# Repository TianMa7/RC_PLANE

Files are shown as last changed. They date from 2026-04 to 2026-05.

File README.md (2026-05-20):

# Fixed-Wing RC Aircraft

<table>
  <tr>
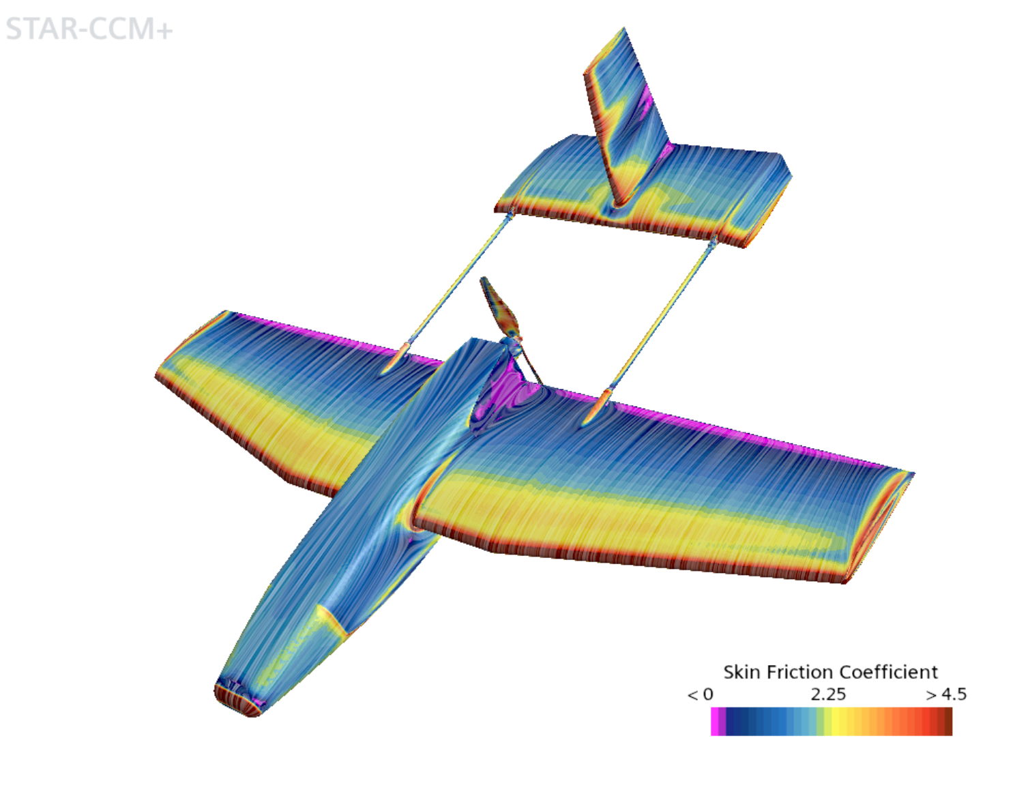
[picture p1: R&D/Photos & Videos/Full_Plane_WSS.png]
    <td width="21.25%"></td>
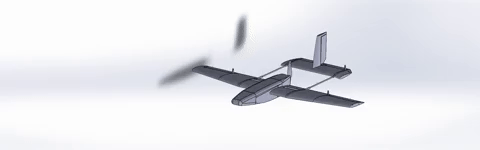
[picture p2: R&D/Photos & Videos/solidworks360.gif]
    <td width="50%"></td>
  </tr>
</table>

## ✈️ Summary and Takeaways
**Mission Goal:** Design and fly an RC Aircraft capable of fly-by-wire controls and stable flight. Learn about nuances of designing systems capable of withstanding the complex dynamics of flight. 

### 📋 Technical Specifications
| Category | Metric |
| :--- | :--- |
| **Wingspan** | 99.25cm |
| **Airfoil** | NACA 2412 |
| **Weight** | 837g |
| **Motor** | 2212 1400kv BLDC Motor |
| **Battery** | 3S 2200 mAh LIPO |
| **Material Cost** | $157 CAD |
| **Materials List** | [Download Excel Sheet](https://github.com/TianMa7/RC_PLANE/raw/master/HARDWARE/RC%20Plane%20-%20Major%20Item%20List.xlsx)

---

### 🛠️ Design & Aerodynamics
<table>
  <tr>
    <td width="50%">
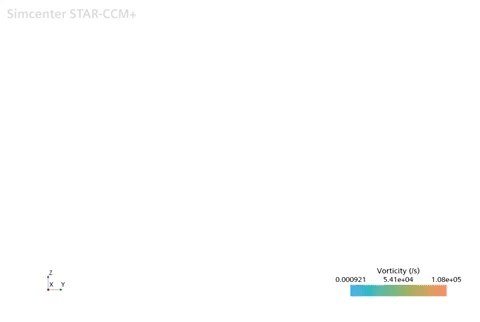
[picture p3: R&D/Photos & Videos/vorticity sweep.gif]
      
      <br><em>Vorticity X Sweep</em>
    </td>
    <td width="50%">
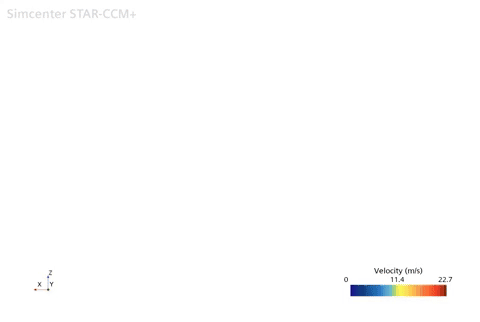
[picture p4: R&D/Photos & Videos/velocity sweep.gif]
      
      <br><em>Velocity Y Sweep</em>
    </td>
  </tr>
</table>

* **Research & Development:** Selection of the NACA 2412 airfoil was driven by the need for a stable lift-to-drag ratio across a variety of Reynolds numbers suitable for small-scale RC flight. Pull-Pull control systems were implemented to reduce and optimize weight distribution.
* **Simulation (CFD):** Star-CCM+ CFD was used to validate design choices and identify potential changes. It was also used to calculate the aerodynamic balance point to determine weight distribution.
* **Mechanical (CAD):** SolidWorks was used to model the aircraft and internal components. Designs were originally considered to be a combination of laser cut balsa wood, composite construction, and 3D printing. Project was gradually descoped to 3D printing and composite components to save manufacturing time and complexity.

### 💻 Systems & Integration
* **Scope:** Development of electronics and control software capable of producing stable, controllable flight for plane. Controls are fly-by-wire for pitch and roll, and raw input for yaw. Communication between radio rx/tx was beyond the scope of the project.
* **Control Logic:** RTOS Implementation of a PID-based control loop taking input from blended IMU data with Mahony filter as well as user input from rc controller. Uses PID loop to maintain stability when external forces are acting upon it.
* **Electronics:** Protoboard containing esp32c3, lsm6ds3, and other components. Controlled a BLDC motor as well as 3 MG90s Servos. A full material list and breakdown can be found [HERE](https://github.com/TianMa7/RC_PLANE/raw/master/HARDWARE/RC%20Plane%20-%20Major%20Item%20List.xlsx).

### 🚀 Validation & Flight Results
* **Pre-Flight:** Aircraft was 16% below maximum calculated weight. Static thrust and controls testing validated structural integrity of the body as well as the electronics. 
* **Maiden Flight:** [Insert Date]
* **Outcome:** EMF interference towards unshielded electronic devices (servo, imu) theorized to be the reason behind unpredictable and unlevel flight/crash. Issue was not flagged as interference only became an issue when motor was facing load from propeller. Bench testing was primarily not conducted with propeller on for safety. Future designs should explore methods of reducing such interference, as well as creating more robust control surfaces and improving software design. Mechanical design will focus on improving aerodynamic efficiency as well as shifting CoG forward for better stability.

---

### 📷 Media Gallery

<table>
  <tr>
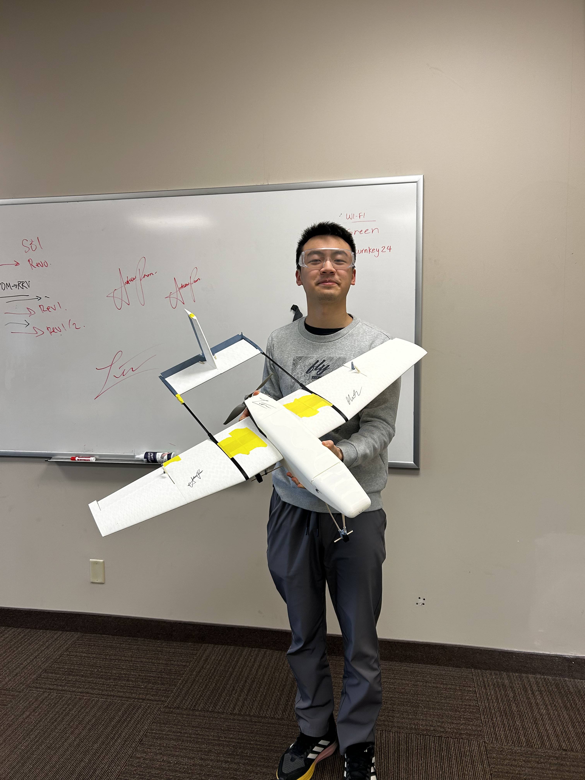
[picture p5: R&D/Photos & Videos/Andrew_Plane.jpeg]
Andrew Plane
    <td width="33%"><br><em>Andrew Plane</em></td>
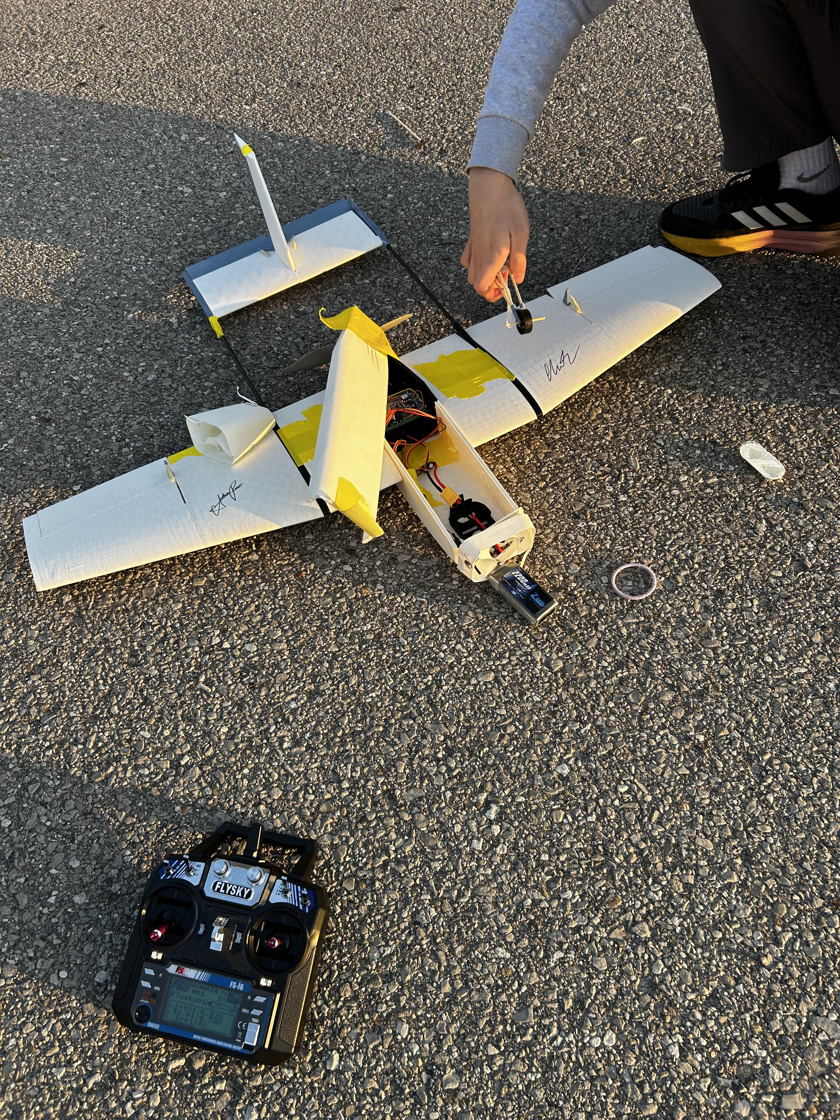
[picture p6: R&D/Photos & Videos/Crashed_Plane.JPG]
Crashed Plane
    <td width="33%"><br><em>Crashed Plane</em></td>
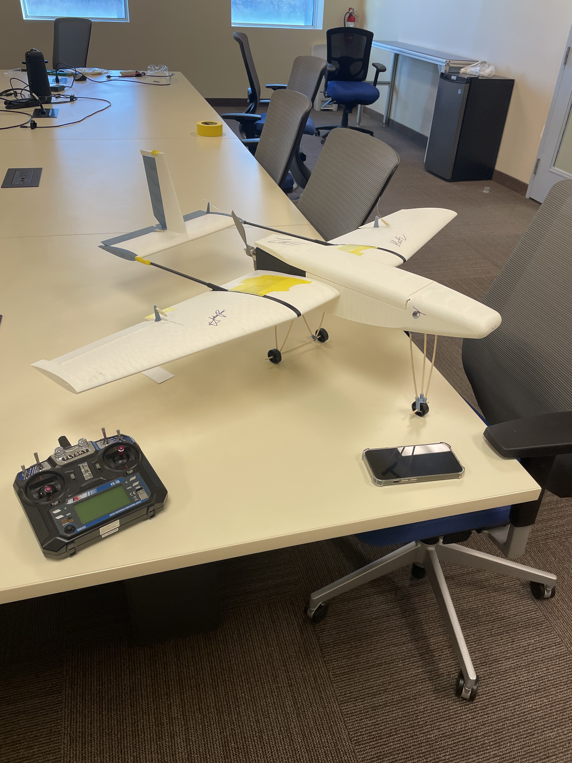
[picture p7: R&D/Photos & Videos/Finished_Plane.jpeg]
Finished Plane
    <td width="33%"><br><em>Finished Plane</em></td>
  </tr>
  <tr>
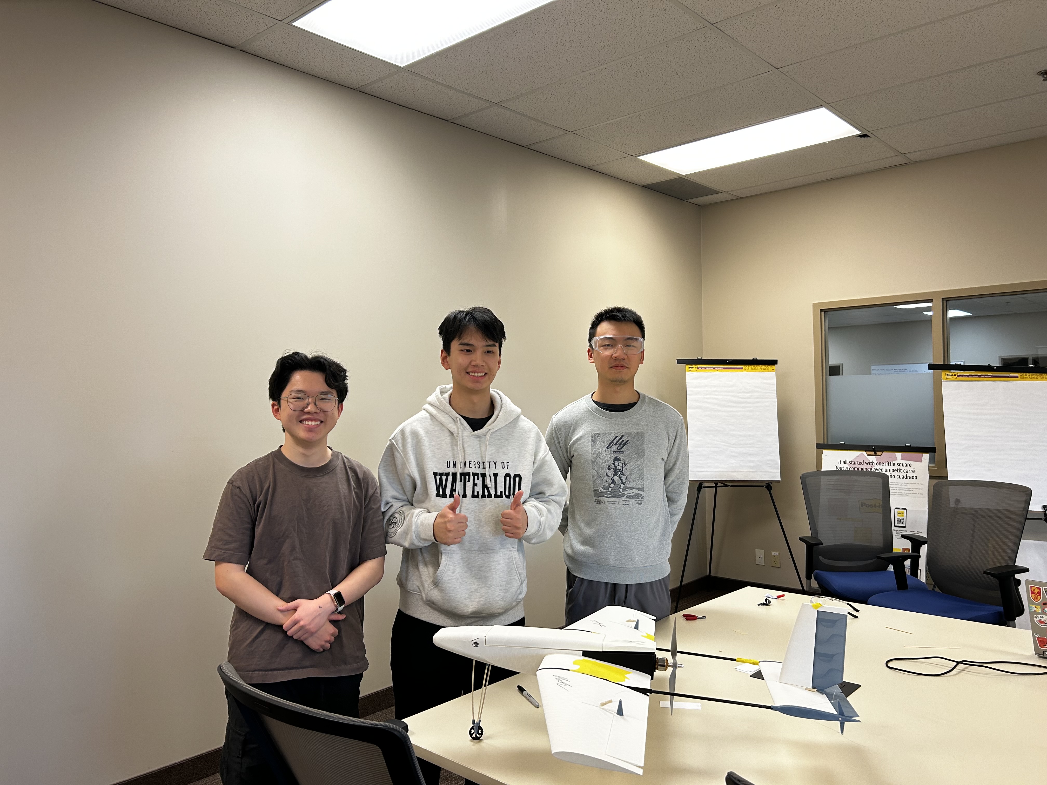
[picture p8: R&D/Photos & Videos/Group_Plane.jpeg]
Group Plane
    <td width="33%"><br><em>Group Plane</em></td>
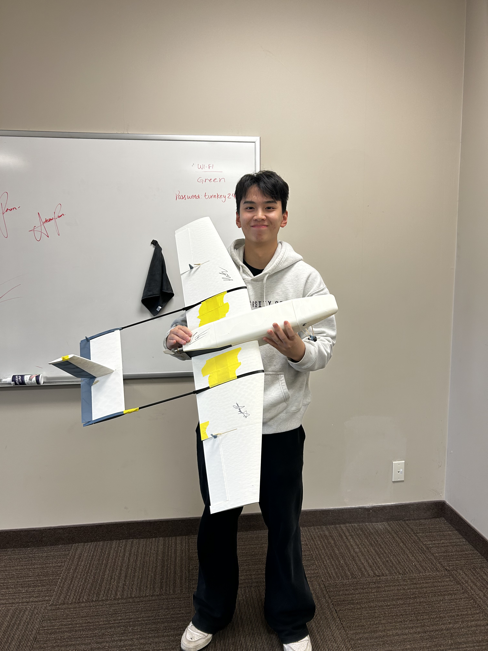
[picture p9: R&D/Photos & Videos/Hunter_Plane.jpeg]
Hunter Plane
    <td width="33%"><br><em>Hunter Plane</em></td>
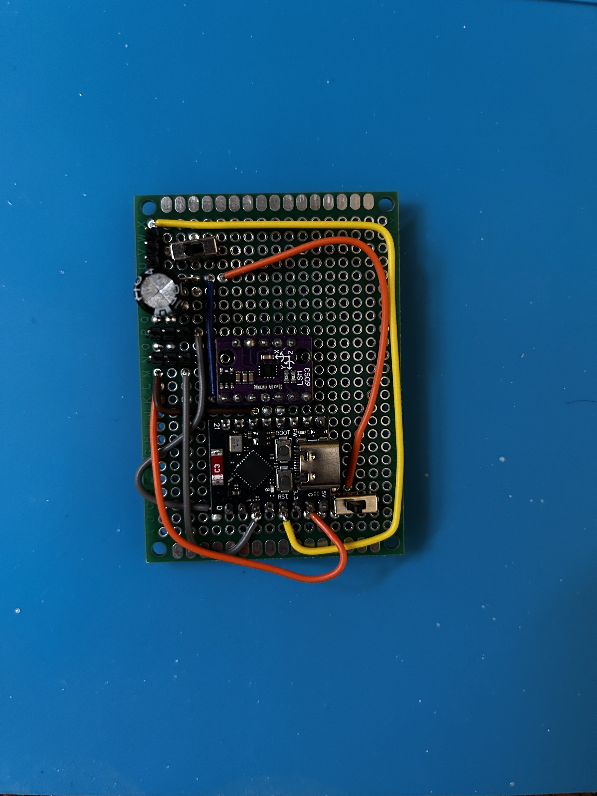
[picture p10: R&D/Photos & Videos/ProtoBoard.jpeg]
Protoboard
    <td width="33%"><br><em>Protoboard</em></td>
  </tr>
  <tr>
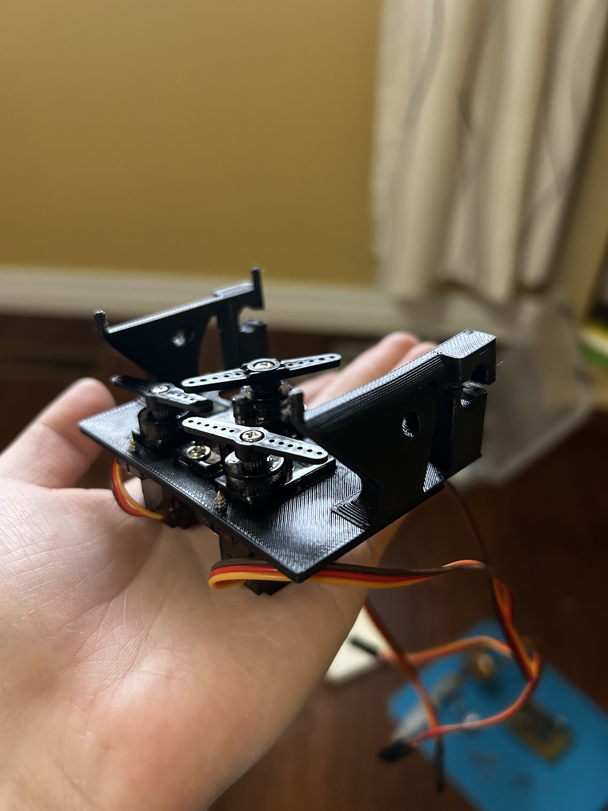
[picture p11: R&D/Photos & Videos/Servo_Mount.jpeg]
Servo Mount
    <td width="33%"><br><em>Servo Mount</em></td>
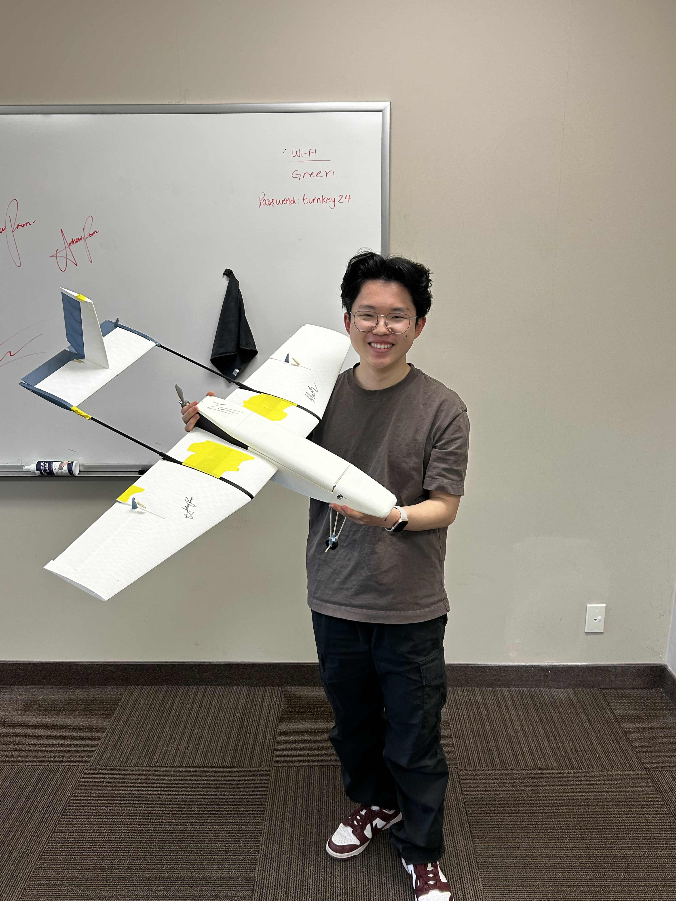
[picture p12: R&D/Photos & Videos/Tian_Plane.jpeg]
Tian Plane
    <td width="33%"><br><em>Tian Plane</em></td>
    <td width="33%">
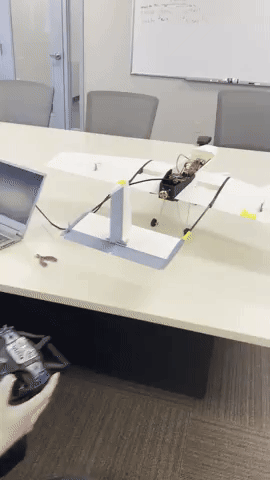
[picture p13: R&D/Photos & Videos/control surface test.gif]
      
      <br><em>Ailerons Test</em>
    </td>
  </tr>
  <tr>
    <td width="33%">
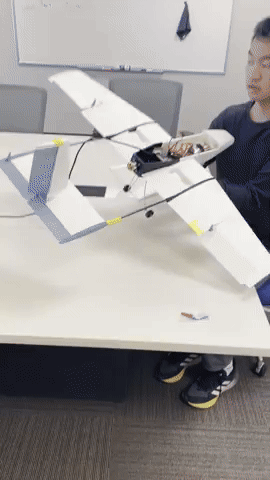
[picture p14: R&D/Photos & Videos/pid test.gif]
      
      <br><em>Auto Balancing Test</em>
    </td>
    <td width="33%">
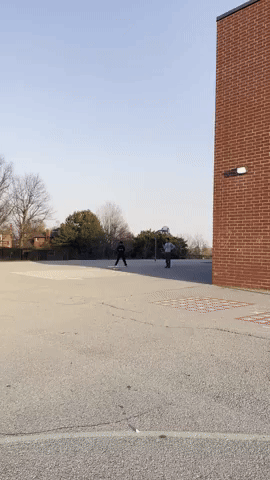
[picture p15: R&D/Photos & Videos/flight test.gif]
      
      <br><em>Flight Test</em>
    </td>
    <td width="33%">
      
      <br><em>360 Overview</em>
    </td>
  </tr>
</table>

---
*Developed by Tian Ma, Hunter Liu, Andrew Poon*

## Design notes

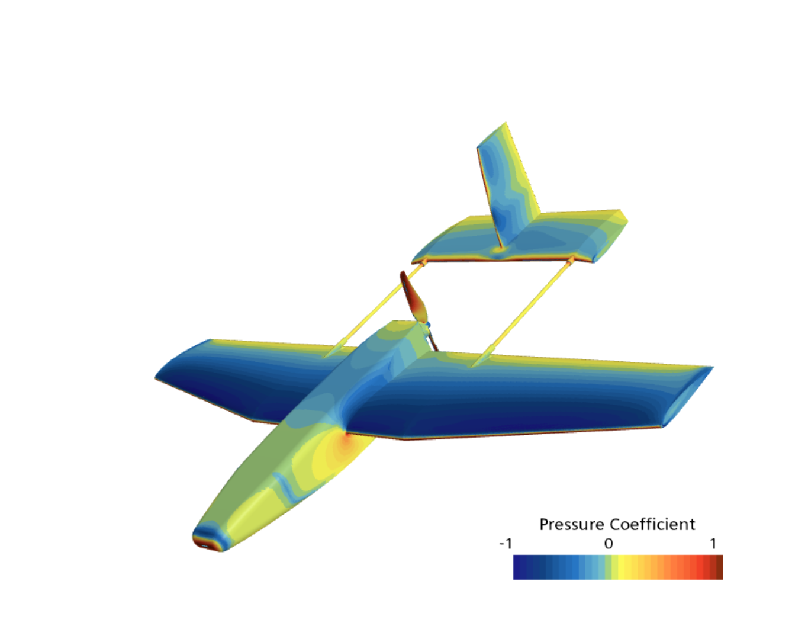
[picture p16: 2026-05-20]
R&D/Photos & Videos/Full_Plane_Pressure_Coefficient.png

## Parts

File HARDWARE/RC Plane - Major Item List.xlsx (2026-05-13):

Item name | Qty | Cost Per Unit | Supplier | Type
ESP32-C3 Microcontroller | 1 | $3.00 | AliExpress | Electronics
LSM6DS3 IMU | 1 | $3.00 | AliExpress | Electronics
2212 1400kv BLDC Motor | 1 | $4.00 | AliExpress | Electronics
8060 Propeller | 1 | $1.25 | AliExpress | Electronics
30a ESC | 1 | $6.00 | AliExpress | Electronics
2200mAh 3s LiPo Battery | 1 | $25.00 | Amazon | Electronics
FlySky FS-i6 6CH RC Controller/Reciever | 1 | $69.00 | AliExpress | Electronics
MG90S Servo | 3 | $4.00 | AliExpress | Electronics
6mm Pultruded carbon tube | 2 | $7.00 | Composites Canada | Material
Creality LW-PLA 1kg roll | 1 | $24.00 | Creality Canada | Material
TPU | 1 | $0.00 | N/A | Material
Generic PLA | 1 | $11.00 | Creality Canada | Material
 | Total Cost | $157.25

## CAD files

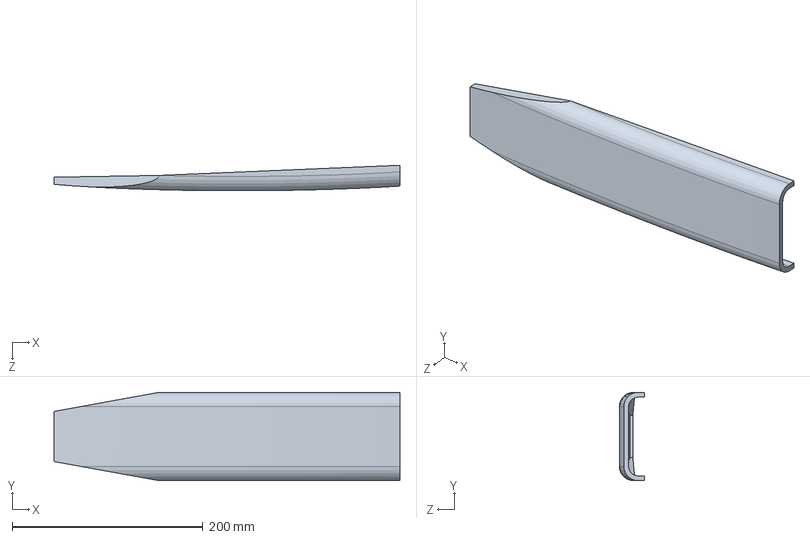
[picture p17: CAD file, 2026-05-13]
HARDWARE/SolidWorks/fuselage_v3_lid_01.SLDPRT
362.6 x 92.5 x 26.7 mm

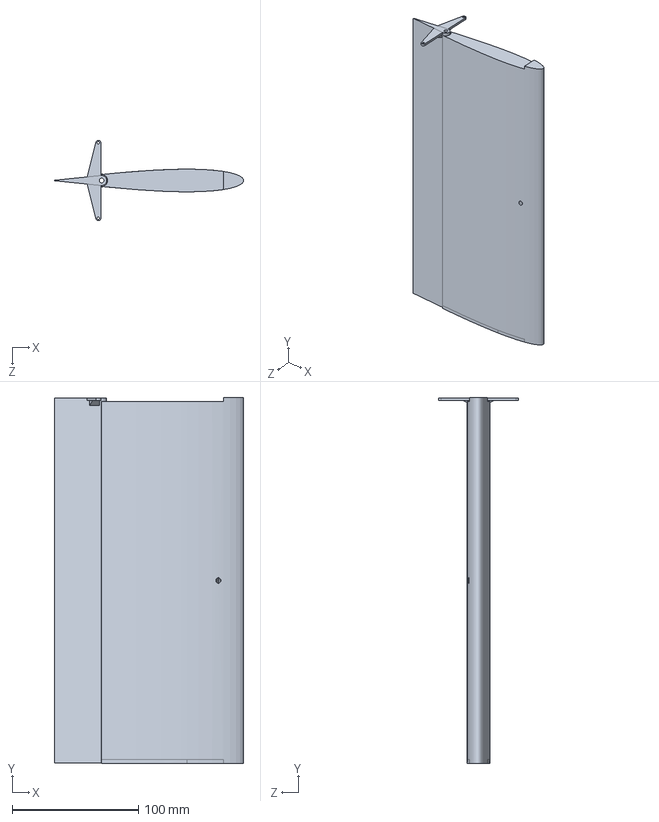
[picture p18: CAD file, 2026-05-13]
HARDWARE/SolidWorks/elevator2.SLDPRT
150.0 x 290.0 x 63.8 mm

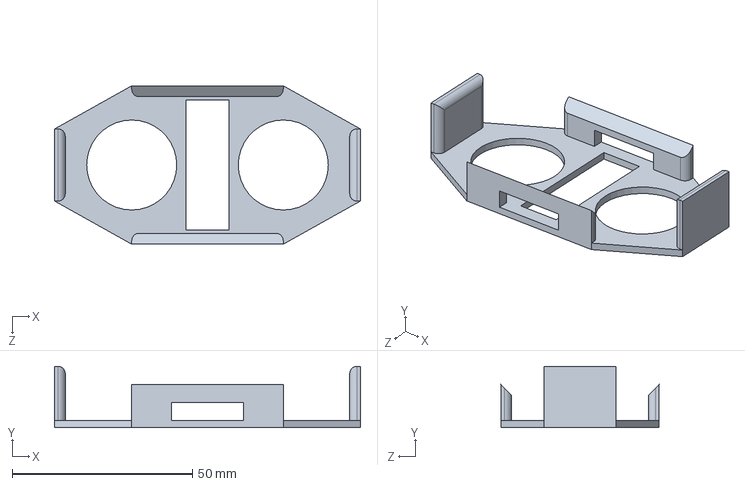
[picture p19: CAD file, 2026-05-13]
HARDWARE/SolidWorks/battery-mount-version-00_PRINT.SLDPRT
85.0 x 17.0 x 44.0 mm

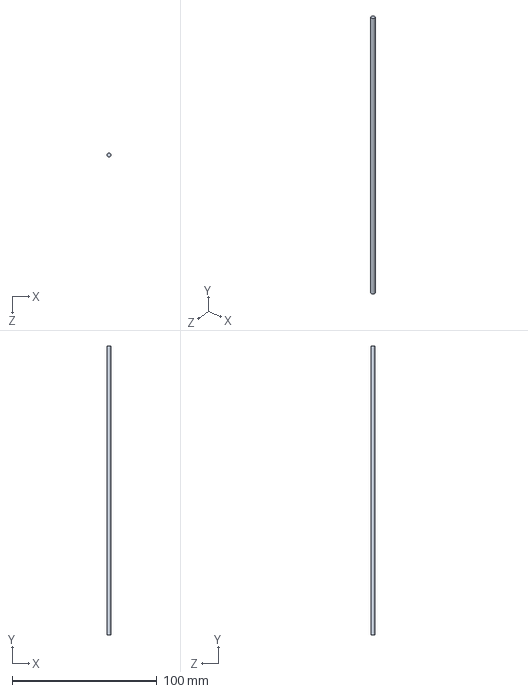
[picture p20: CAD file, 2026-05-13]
HARDWARE/SolidWorks/BAMBOO-SKEWER-3MM.SLDPRT
3.00 x 200.0 x 3.00 mm

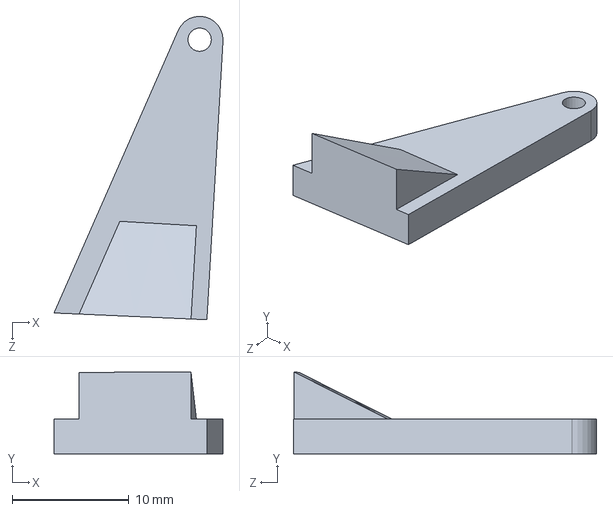
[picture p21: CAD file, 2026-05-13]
HARDWARE/SolidWorks/WingHornLower.SLDPRT
14.5 x 7.00 x 26.0 mm

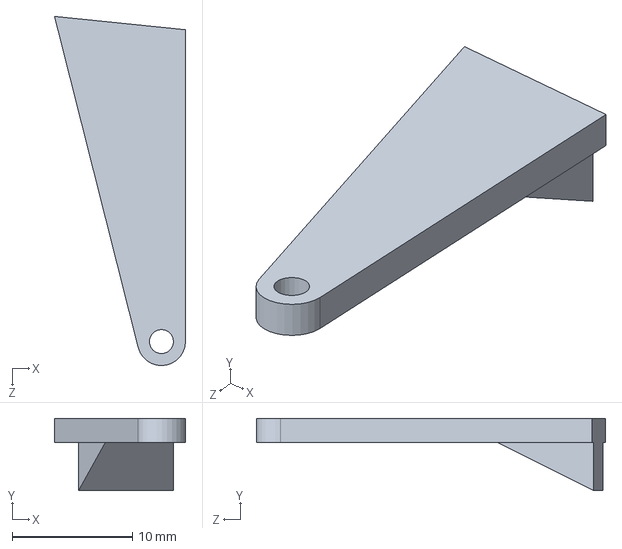
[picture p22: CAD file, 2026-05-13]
HARDWARE/SolidWorks/AileronHornUpper.SLDPRT
10.9 x 6.00 x 29.0 mm

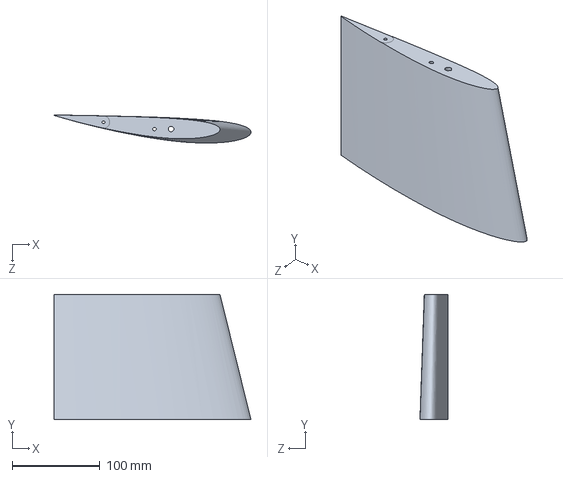
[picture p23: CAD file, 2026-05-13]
HARDWARE/SolidWorks/Body2.SLDPRT
224.2 x 142.6 x 32.0 mm

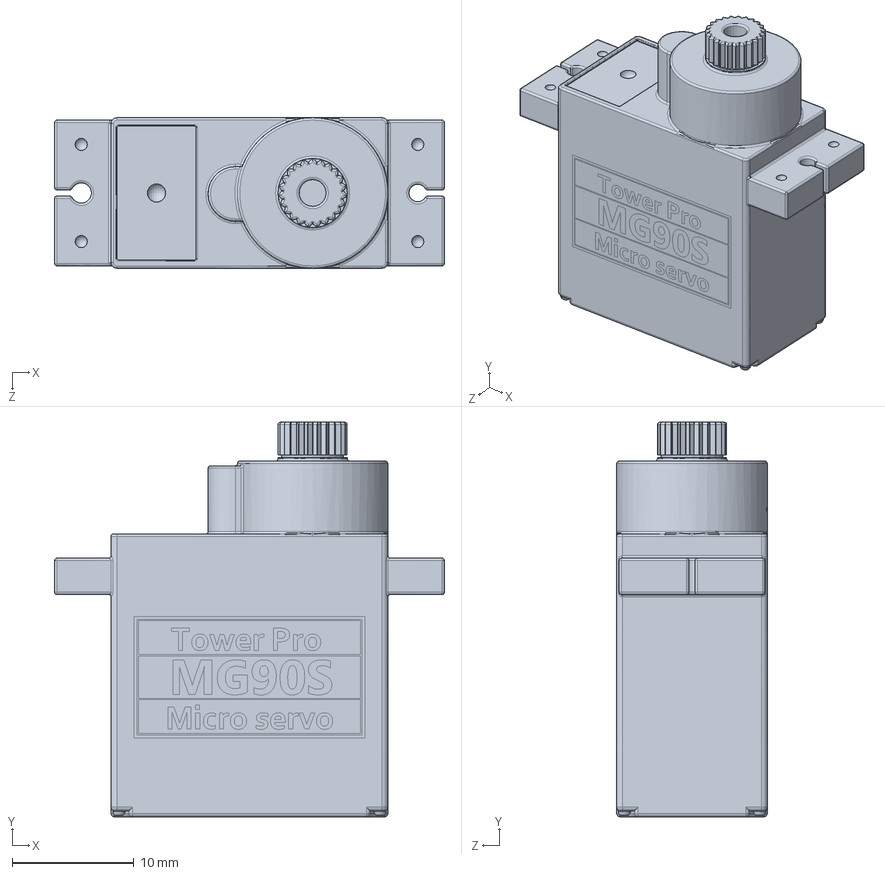
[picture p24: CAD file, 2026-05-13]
HARDWARE/SolidWorks/Tower-Pro-MG90S.SLDPRT
32.1 x 32.5 x 12.4 mm

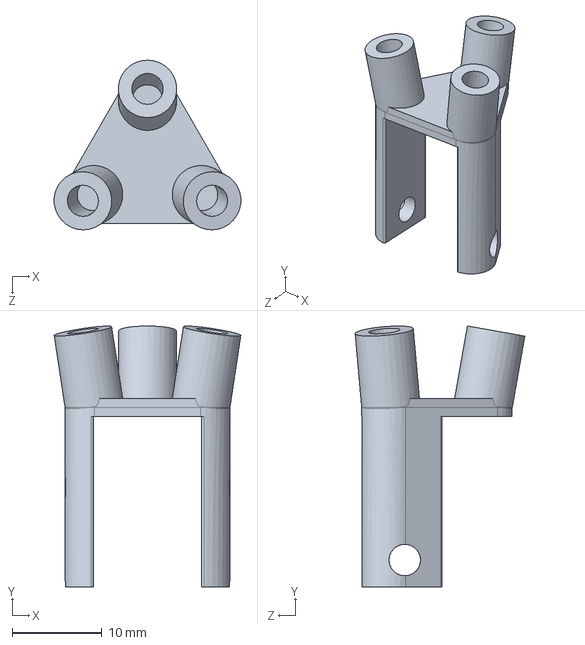
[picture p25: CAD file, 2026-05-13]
HARDWARE/SolidWorks/nose_gear.SLDPRT
20.8 x 29.1 x 18.9 mm

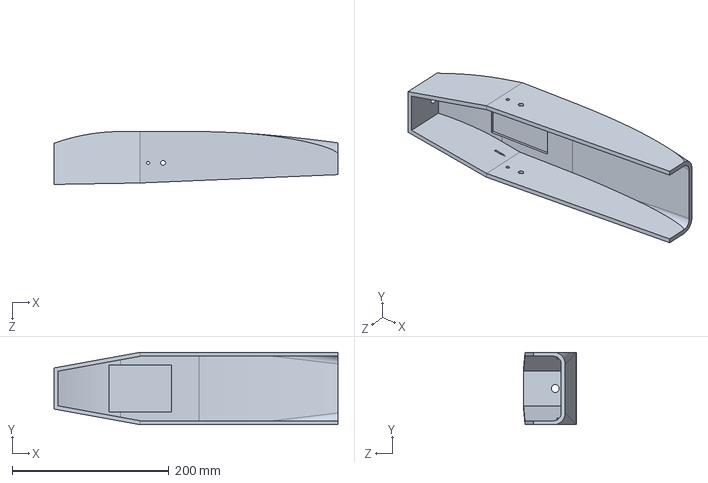
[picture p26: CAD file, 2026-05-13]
HARDWARE/SolidWorks/fuselage_v3_body_01.SLDPRT
362.6 x 92.5 x 67.5 mm

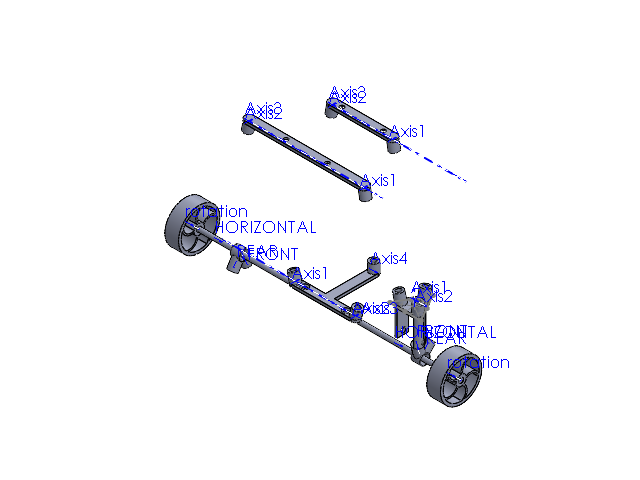
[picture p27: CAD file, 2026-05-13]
HARDWARE/SolidWorks/landing gear comp.SLDASM
BAMBOO-SKEWER-3MM
TIRE-30MM x 2
MOUNTING CONNECTOR x 2
ROD-CONNECTOR-3.5MM x 2
nose_gear
MOUNTING CONNECTOR-nose

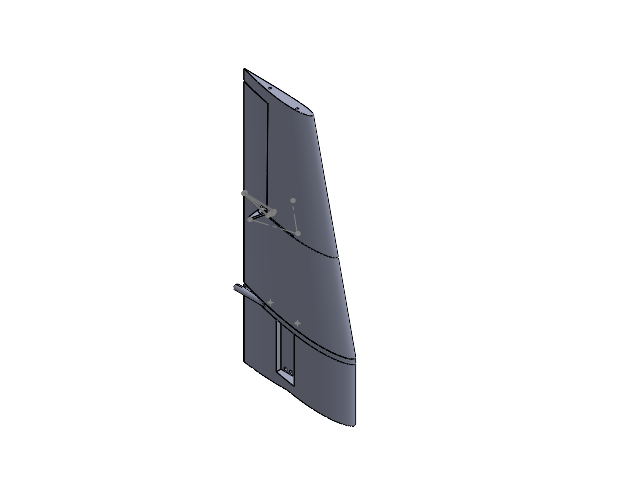
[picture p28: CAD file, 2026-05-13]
HARDWARE/SolidWorks/Wing_asssy_v1.SLDASM
Wing_MidSection_v1
Wingtip_v1
wing_root_v2

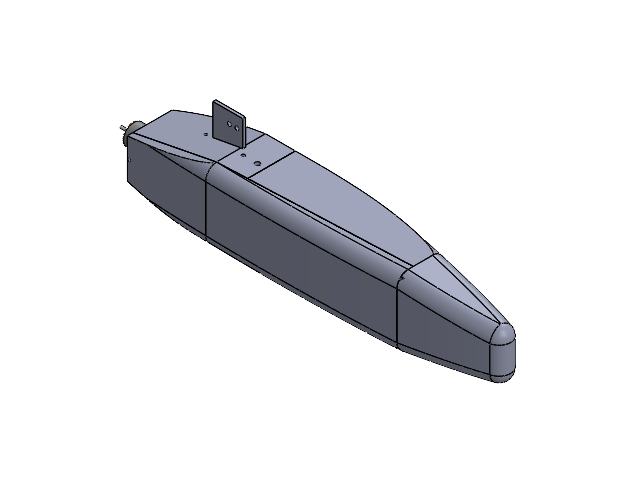
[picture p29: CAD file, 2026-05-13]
HARDWARE/SolidWorks/fuselage_asm.SLDASM
fuselage_V3
servo-mount-version-02_PRINT
DOTTED PCB 5 7 CM
Tower-Pro-MG90S x 3
MG90S 9g Micro Servo Medium Horn 12 holes x 3
servo-mount-rings x 4
motor-mount-version-03
Motor_BLDC_2212,6T_2200KV
Generic.40A.ESC.stp
battery-mount-version-00_PRINT

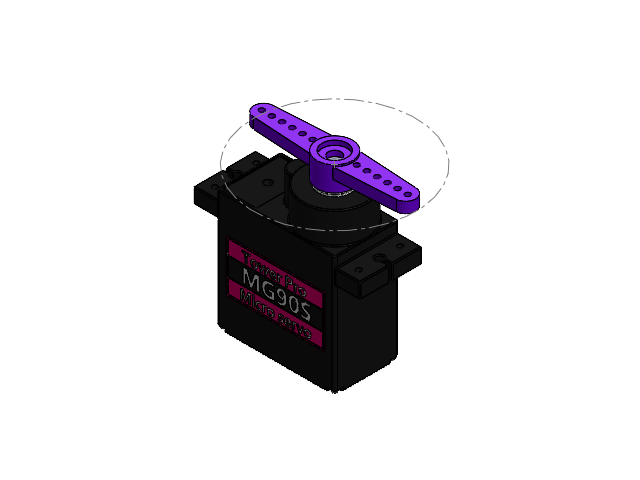
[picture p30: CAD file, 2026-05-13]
HARDWARE/SolidWorks/mg90s_assembly.SLDASM
Tower-Pro-MG90S
MG90S 9g Micro Servo Medium Horn 12 holes

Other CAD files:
HARDWARE/SolidWorks/MirrorWing_asssy_v1.SLDASM
HARDWARE/SolidWorks/Full_Plane_Assy.SLDASM
HARDWARE/SolidWorks/servo_asm_2.SLDASM
HARDWARE/SolidWorks/AileronHornLower.SLDPRT
HARDWARE/3mf/Full_Plane_Assy.3mf
HARDWARE/SolidWorks/8060_propeller.SLDPRT
HARDWARE/SolidWorks/Body1.SLDPRT
HARDWARE/SolidWorks/Carbon_rods.SLDPRT
HARDWARE/SolidWorks/DOTTED PCB 5 7 CM.SLDPRT
HARDWARE/SolidWorks/Elavator_attachment.SLDPRT
HARDWARE/SolidWorks/Elevator_v1.SLDPRT
HARDWARE/SolidWorks/Generic.40A.ESC.stp
HARDWARE/SolidWorks/MG90S 9g Micro Servo Medium Horn 12 holes.SLDPRT
HARDWARE/SolidWorks/MOUNTING CONNECTOR-nose.SLDPRT
HARDWARE/SolidWorks/MOUNTING CONNECTOR.SLDPRT
HARDWARE/SolidWorks/MirrorElavator_attachment.SLDPRT
HARDWARE/SolidWorks/MirrorWing_MidSection_v1.SLDPRT
HARDWARE/SolidWorks/MirrorWingtip_v1.SLDPRT
HARDWARE/SolidWorks/Mirrorwing_root_v2.SLDPRT
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

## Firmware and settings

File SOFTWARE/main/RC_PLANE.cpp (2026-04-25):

/* =============================================================
 * GENERAL HEADERS
 * ============================================================= */
#include <algorithm>
#include <cmath>

/* =============================================================
 * ESP32S3 SPECIFIC HEADERS
 * ============================================================= */
#include "esp_log.h"
#include "freertos/FreeRTOS.h"
#include "freertos/task.h"
#include "freertos/semphr.h"
#include <driver/uart.h>

/* =============================================================
 * SENSOR AND CONTROL HEADERS
 * ============================================================= */
#include "controlTasks.h"
#include "driver/i2c_master.h"
#include "lsm6ds3.h"
#include "mahony_filter.h"
#include "iot_servo.h"
#include "pid.h"


extern "C"
{
#include "ibus/ibus.h"
}

extern "C" void app_main()
{
    ESP_LOGI(TAG, "Starting RC Plane Application");


    /* ---- I2C master bus ---- */
    i2c_master_bus_config_t i2c_mst_config =
    {
        .i2c_port = I2C_NUM_0,
        .sda_io_num = I2C_MASTER_SDA_IO,
        .scl_io_num = I2C_MASTER_SCL_IO,
        .clk_source = I2C_CLK_SRC_DEFAULT,
        .glitch_ignore_cnt = 7,
        .intr_priority = 0,
        .trans_queue_depth = 0,
        .flags =
     {
            .enable_internal_pullup = true,
            .allow_pd = false
        },
    };

    i2c_master_bus_handle_t bus_handle;
    esp_err_t ret = i2c_new_master_bus(&i2c_mst_config, &bus_handle);
    if (ret != ESP_OK)
    {
        ESP_LOGE(TAG, "I2C bus failed: %s", esp_err_to_name(ret));
        while (true)
        {
            vTaskDelay(pdMS_TO_TICKS(1000));
        }
    }
    ESP_LOGI(TAG, "I2C bus OK");
    /* ---- end I2C master bus ---- */

    /* ---- LSM6DS3 sensor ---- */
    lsm6ds3_config_t imu_config =
    {
        .i2c_bus_handle = bus_handle,
        .i2c_freq_hz    = I2C_MASTER_FREQ_HZ,
        .device_address  = LSM6DS3_ADDR_SA0_HIGH,
    };

    lsm6ds3_handle_t imu_handle;
    ret = lsm6ds3_init(&imu_config, &imu_handle);
    if (ret != ESP_OK)
    {
        ESP_LOGE(TAG, "LSM6DS3 init failed: %s", esp_err_to_name(ret));
        i2c_del_master_bus(bus_handle);
        while (true)
        {
            vTaskDelay(pdMS_TO_TICKS(1000));
        }
    }
    ESP_LOGI(TAG, "LSM6DS3 OK");
    /* ---- end LSM6DS3 sensor ---- */



    /* ---- servo control ---- */
    /* Adjust frequency as needed */
    servo_config_t servo_config = {
        .max_angle = 180,
        .min_width_us = 500,
        .max_width_us = 2500,
        .freq = 50,
        .timer_number = LEDC_TIMER_0,
        .channels = {
            .servo_pin =
         {
                AILERON_SERVO_PIN,
                ELEVATOR_SERVO_PIN,
            },
            .ch =
         {
                LEDC_CHANNEL_0,
                LEDC_CHANNEL_1
            }
        },
        .channel_number = 2,
    };

    ret = iot_servo_init(LEDC_LOW_SPEED_MODE, &servo_config);
    if (ret != ESP_OK)
    {
        ESP_LOGE(TAG, "Servo init failed: %s", esp_err_to_name(ret));
        lsm6ds3_deinit(imu_handle);
        i2c_del_master_bus(bus_handle);
        while (true)
        {
            vTaskDelay(pdMS_TO_TICKS(1000));
        }
    }
    ESP_LOGI(TAG, "Servo OK");
    /* ---- end servo control ---- */

    /* ---- IBUS setup ---- */
    uart_lowlevel_config config;
    config.port = IBUS_UART;
    config.tx_pin = UART_PIN_NO_CHANGE; // Not transmitting, so leave TX unconfigured
    config.rx_pin = IBUS_RX_PIN;
    ibus_context_t cfx = ibus_init(&config);
    if (cfx == nullptr)
    {
        ESP_LOGE(TAG, "IBUS init failed");
        ibus_set_channel_handler(cfx, nullptr, nullptr); // Unset handler if init failed
        iot_servo_deinit(LEDC_LOW_SPEED_MODE);
        lsm6ds3_deinit(imu_handle);
        i2c_del_master_bus(bus_handle);
        while (true)
        {
            vTaskDelay(pdMS_TO_TICKS(1000));
        }
    }
    ESP_LOGI(TAG, "IBUS OK");
    /* ---- end IBUS setup ---- */

    static CONTROLTASKS controlTasks(imu_handle);
    ibus_set_channel_handler(cfx, CONTROLTASKS::channel_handler, nullptr);

    BaseType_t ok = xTaskCreate(
        CONTROLTASKS::flightControlTask, //function
        "flight_control_task", //task name
        4096, //allocated memory
        nullptr, //pvParameters
        10, //priority, higher is more important
        nullptr //task handler
    );

    if (ok != pdPASS)
    {
        ESP_LOGE(TAG, "failed to create flight control task");
        while (true)
        {
            vTaskDelay(pdMS_TO_TICKS(1000));
        }
    }

    BaseType_t log_ok = xTaskCreate(
    CONTROLTASKS::logTask,
    "flight_log_task",
    4096,
    nullptr,
    3,
    nullptr
    );

    if (log_ok != pdPASS)
    {
        ESP_LOGE(TAG, "failed to create log task");
    }



}

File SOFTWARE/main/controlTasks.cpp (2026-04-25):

#include "controlTasks.h"
SemaphoreHandle_t CONTROLTASKS::FlightDataMutex = nullptr;
FlightData CONTROLTASKS::planeData = {};
MahonyFilter* CONTROLTASKS::mahony = nullptr;
lsm6ds3_handle_t CONTROLTASKS::imu_handle = nullptr;
PID* CONTROLTASKS::aileronPID = nullptr;
PID* CONTROLTASKS::elevatorPID = nullptr;

CONTROLTASKS::CONTROLTASKS(lsm6ds3_handle_t &imu)
{
        /* Create mutex to lock flight data */
        FlightDataMutex = xSemaphoreCreateMutex();
        if (FlightDataMutex == nullptr)
        {
                ESP_LOGE(TAG, "Failed to create mutex: flightDataMutex");
                return;
        }

        /* init imu and mahony filter */
        imu_handle = imu;

        // Baseline Mahony gains from loop rate for fixed-wing bench bring-up.
        // Formula: kp ~= 2 / settle_time, ki ~= kp / loop_hz.
        const float loop_hz = 1000.0f / planeData.flightControlTaskPeriod_ms;
        const float settle_time_s = 1.2f;
        const float mahony_kp = std::clamp(2.0f / settle_time_s, 0.8f, 2.5f);
        const float mahony_ki = std::clamp(mahony_kp / loop_hz, 0.001f, 0.05f);

        mahony = new MahonyFilter(mahony_kp, mahony_ki);

        if (imu_handle == nullptr || mahony == nullptr)
        {
                ESP_LOGE(TAG, "Failed to create MahonyFilter");
                return;
        }

        ESP_LOGI(TAG, "Mahony gains: Kp=%.3f Ki=%.3f (loop %.1f Hz)",
                 mahony_kp, mahony_ki, loop_hz);

        /* end imu and manhony filter init */
}

CONTROLTASKS::~CONTROLTASKS()
{
        vSemaphoreDelete(FlightDataMutex);
        FlightDataMutex = nullptr;
}

//maps joystick movement to desired output (pwm signal to restricted angle)
inline void CONTROLTASKS::joystickMap(uint16_t control_in, float max_up, float max_down, float& angle)
{
        const int midpoint = 1500; //PWM signal midpoint
        const int deadband = 50; //deadband to prevent jittering

        float inputDiff = midpoint - control_in;
        if (abs(inputDiff) < deadband)
        {
                // Joystick is in the deadband, treat as neutral
                angle = 0;
        }
        else
        {
                // Joystick is pushed down
                angle = inputDiff / 500.0f * max_up; // Scale to max_up_up
        }
}

/* IBUS channel config */
void CONTROLTASKS::channel_handler(ibus_channel_t *channels, void *cookie)
{
        //check if mutex can be taken
        if (xSemaphoreTake(FlightDataMutex, 0) == pdTRUE)
        {
                //updates joystick inputs for pitch and roll
                joystickMap(channels[0].value, 30, 30, planeData.rollTarget);
                joystickMap(channels[1].value, 30, 30, planeData.pitchTarget);

                // joystickMap(channels[4].value, 180, 0, planeData.aileronTrim);
                // joystickMap(channels[5].value, 180, 0, planeData.elevatorTrim);

                /* ADD CONNECTIONS TO CHANNEL 5-6 AS WELL LATER FOR AUX USE */
                planeData.last_ibus_timestamp_ms = pdTICKS_TO_MS(xTaskGetTickCount());
                planeData.is_ibus_failsafe_active = false;

                //return mutex
                xSemaphoreGive(FlightDataMutex);
        }
}

//freertos task for flight control
void CONTROLTASKS::flightControlTask(void* pvParameters)
{
        //init all flight control specific tasks
        TickType_t lastWake = xTaskGetTickCount();

        //init aileron and elevator pid controls
        if (xSemaphoreTake(FlightDataMutex, pdMS_TO_TICKS(1000)) == pdFALSE)
        {
                ESP_LOGE(TAG, "Failed to take mutex for PID setup");
                return;
        }
        aileronPID = new PID(planeData.flightControlTaskPeriod_s,
                             planeData.aileronUpTravel,
                             -planeData.aileronDownTravel,
                             planeData.KpAileron, planeData.KiAileron,
                             planeData.KdAileron, 0.0f);
        elevatorPID = new PID(planeData.flightControlTaskPeriod_s,
                              planeData.elevatorUpTravel,
                              -planeData.elevatorDownTravel,
                              planeData.KpElevator, planeData.KiElevator,
                              planeData.KdElevator, 0.0f);
        float period = planeData.flightControlTaskPeriod_ms;

        xSemaphoreGive(FlightDataMutex);

        if (aileronPID == nullptr || elevatorPID == nullptr)
        {
                ESP_LOGE(TAG, "Failed to create PID objects");
                return;
        }
        // //end pid init

        //main control loop
        while (true)
        {
                IBUSfailsafe();
                readIMU();
                moveServos();

                vTaskDelayUntil(&lastWake, pdMS_TO_TICKS(period));
        }
}

inline void CONTROLTASKS::IBUSfailsafe()
{
        uint32_t now = pdTICKS_TO_MS(xTaskGetTickCount());

        if (xSemaphoreTake(FlightDataMutex, 0) == pdTRUE)
        {
                if (now - planeData.last_ibus_timestamp_ms > planeData.failsafeTimeout_ms)
                {
                        planeData.pitchTarget = 0;
                        planeData.rollTarget = 0;
                        planeData.is_ibus_failsafe_active = true;
                }
                xSemaphoreGive(FlightDataMutex);
        }
}
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

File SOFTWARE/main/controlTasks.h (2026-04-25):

#pragma once
/* =============================================================
 * GENERAL HEADERS
 * ============================================================= */
#include <algorithm>
#include <cmath>

/* =============================================================
 * ESP32S3 SPECIFIC HEADERS
 * ============================================================= */
#include "esp_log.h"
#include "freertos/FreeRTOS.h"
#include "freertos/task.h"
#include "freertos/semphr.h"
#include <driver/uart.h>

/* =============================================================
 * SENSOR AND CONTROL HEADERS
 * ============================================================= */
#include "driver/i2c_master.h"
#include "lsm6ds3.h"
#include "mahony_filter.h"
#include "iot_servo.h"
#include "pid.h"

/* configurations */
#include "flightCfg.h"

extern "C"
{
#include "ibus/ibus.h"
}

/* --------- SHARED RESOURCES ---------- */
struct FlightData
{
 //Current Orientation - IMU
 float pitchCurrent = 0;
 float rollCurrent = 0;

 //Target Orientation - IBUS
 float pitchTarget = 0;
 float rollTarget = 0;

 // Conservative baseline PID gains for first flight tuning.
 float KpAileron = 1.500f;
 float KiAileron = 0.008f;
 float KdAileron = 0.060f;

 float KpElevator = 3.000f;
 float KiElevator = 0.010f;
 float KdElevator = 0.075f;

 //Trim tuning values
 float elevatorTrim = 90;
 float aileronTrim = 90;

 // Allowed servo travel around trim (servo-deg).
 float aileronUpTravel = 80;
 float aileronDownTravel = 80;
 float elevatorUpTravel = 80;
 float elevatorDownTravel = 80;

 //command values
 float cmdAileron = aileronTrim;
 float cmdElevator = elevatorTrim;

 //Failsafe flag
 uint32_t last_ibus_timestamp_ms = 0;
 uint32_t last_imu_timestamp_ms = 0;
 int failsafeTimeout_ms = 150;
 bool is_ibus_failsafe_active = true;
 bool is_imu_failsafe_active = true;

 //dT ----> WHAT DOES THIS DO??????
 float flightControlTaskPeriod_ms = 10;
 float flightControlTaskPeriod_s = flightControlTaskPeriod_ms / (1000.0f); //20ms loop period, convert to seconds for PID calculations
};//stores global flight-related data

class CONTROLTASKS
{
 public:
 CONTROLTASKS(lsm6ds3_handle_t &imu);
 ~CONTROLTASKS();

 static void flightControlTask(void * pvParameters);
 static void logTask(void * pvParameters);
 /* IBUS channel config */
 static void channel_handler(ibus_channel_t *channels, void *cookie);

 private:

 //helper functions
 static void joystickMap (uint16_t control_in, float max_up, float max_down, float &angle);
 static void IBUSfailsafe();
 static void readIMU();
 static void moveServos();

 //objects
 static SemaphoreHandle_t FlightDataMutex; //initialize a mutex to prevent multiple access to planeData
 static FlightData planeData; //initialize a struct containing data for plane
 static MahonyFilter *mahony; //mahony filter object
 static lsm6ds3_handle_t imu_handle;//handle for imu task
 static PID *aileronPID; //pid object for aileron control
 static PID *elevatorPID;//pid object for elevator control



 //move shit from the flightData Struct into here

};

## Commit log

2026-05-13 Added hardware section
    [8060_propeller.SLDPRT, AileronHornLower.SLDPRT, AileronHornUpper.SLDPRT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]
2026-05-13 Enhance README with project details and specifications
    Added detailed project overview, technical specifications, design considerations, systems integration, and validation results for the fixed-wing RC aircraft.
2026-05-13 Revise README with updated project details and findings
    Updated project summary, technical specifications, and validation results for the Fixed-Wing RC Aircraft. Added details on fabrication, control logic, and outcomes from pre-flight tests.
2026-05-13 Update wingspan and battery specifications in README
2026-05-13 Added Excel sheet for bom
    [RC Plane - Major Item List.xlsx]
2026-05-20 Added pressure coeffiencent photo of whole plane
